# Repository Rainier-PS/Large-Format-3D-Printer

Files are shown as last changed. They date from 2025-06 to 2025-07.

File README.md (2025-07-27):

# Large Format Cartesian 3D Printer

## Project Overview
This is a custom-built large-format Cartesian 3D printer designed for high-quality DIY fabrication with a competitive edge against commercial systems.

### Key Specs
- **Build Volume:** 310 x 310 x 340 mm
- **Motion System:** Cartesian XYZ
- **Controller:** Arduino Mega 2560 + RAMPS 1.4
- **Stepper Drivers:** TMC2209 (ultra-quiet and reliable)
- **Firmware:** Marlin 2.1.2 (custom configuration)
- **Extruder & Hotend:** MK8 extruder + hotend kit
- **Bed:** 24V heated aluminum bed with PEI sheet
- **PSU:** Mean Well LRS-350-24

---

## Why I Made This Project

I wanted to build a production-grade 3D printer that is not only budget-friendly, but also offers a large build area, solid mechanical reliability, and excellent print quality.

This project also serves as a hands-on learning experience where I could improve my skills in:
- **Electronics assembly and integration**
- **CAD modeling and mechanical design**
- **Firmware configuration (Marlin)**
- **Wiring, troubleshooting, and system-level design**

The Hack Club Highway event was the perfect place to begin this journey. With mentorship, resources, and motivation to build something real from the ground up.

Ultimately, I wanted this printer to be **good enough to use as my daily driver**: a machine I can rely on for future projects, prototypes, and creative builds beyond the event itself.

---

## Project Gallery

---

### 3D CAD Model
> *Simplified CAD model for structural representation only. Some non-critical details (e.g., pulleys, belts, LCD) were omitted for simplicity*
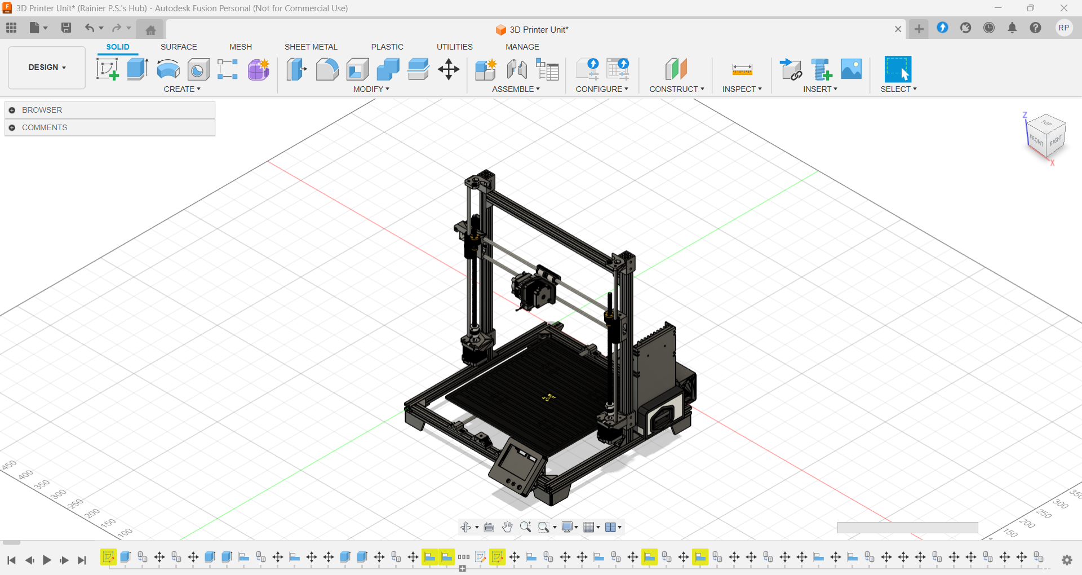
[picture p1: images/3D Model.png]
cad_screenshot


---

### Wiring Diagram
> *Schematic of wiring between Arduino Mega, RAMPS board, endstops, stepper motors, thermistors, and heated bed.*
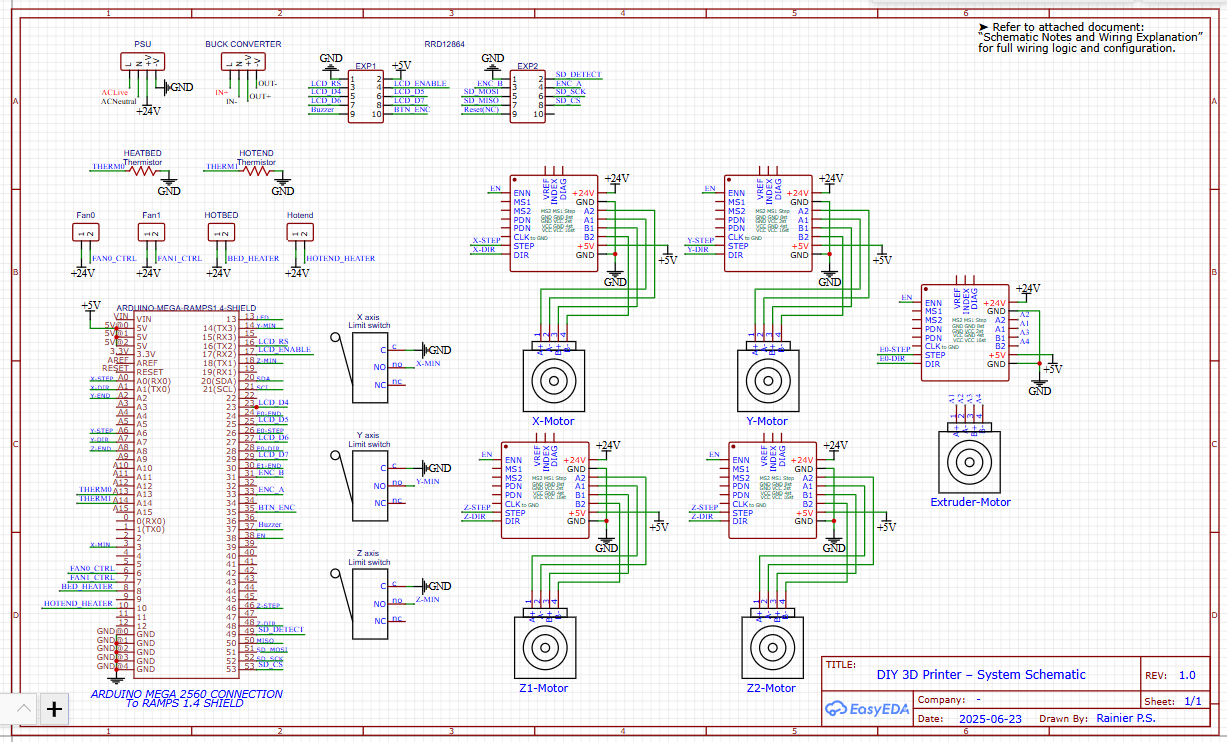
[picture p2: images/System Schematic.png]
wiring_diagram


---

## Wiring Overview  
- **Controller**: Arduino Mega 2560 + RAMPS 1.4  
- **Power**: 24V PSU → RAMPS, 12V buck → Arduino  
- **Endstops**: X, Y, Z (NO → `MIN` pins)  
- **Thermistors**: Hotend (`A13`), Bed (`A14`)  
- **Steppers**: X, Y, Z (dual), E (TMC2209 legacy)  
- **Fans**: Hotend cooling, Electronics cooling  
- **Heaters**: Hotend (`D10`), Bed (`D8`)  

> *[Full wiring details](docs/Schematic%20Notes%20and%20Wiring%20Explanation.txt)*

---

## Bill of Materials (BOM)

| No. | Category | Item | Quantity | Est. Price (USD) | Description / Notes | Link |
|-----|---|---|---|---|---|---|
| 1 | Frame & Structure | 2020 Aluminum Extrusion – 6 m | 1 | $20 | Not Pre-Cut | [Link](https://www.tokopedia.com/aluminiumprofileid/aluminium-extrusion-2020-t-slot-silver-panjang-6-meter-sangat-murah-dan-berkualitas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) |
| 2 | Frame & Structure | Corner Brackets | 10 | $2 | L-Brackets | [Link](https://www.tokopedia.com/leansigma/alumunium-bracket-corner-siku-2020-gusset-corner-profile-2020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) |
| 3 | Frame & Structure | Screws (M5) | 100 pcs | $6 | For frame + brackets | [Link](https://www.tokopedia.com/suburbaut/baut-l-baja-grade-12-9-129-m5x10-m5x12-m5x16-m5x20-m5x25-5-x-10-5-x-12-5-x-16-5-x-20-5-x-25-5x10-5x12-5x16-5x20-5x25-full-drat-bl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) |
| 4 | Frame & Structure | T-nuts (M5) | 100 pcs | $2 | For attaching frame components | [Link](https://www.tokopedia.com/cyber-mm/100pcs-t-nut-m5-baja-karbon-20-series-standar-eropa-10-6-5mm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) |
| 5 | Frame & Structure | Screws (M3) | 100 pcs | $4 | For printed parts & mounts | [Link](https://www.tokopedia.com/3dinjakarta/baut-l-baja-hitam-m3x5-m3x10-m3x16-m3x20-hex-socket-screw-din912-black-steel-m3-x-5-m3-x-10-m3-x-16-m3-x-20-m3x16-eacb6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) |
| 6 | Frame & Structure | Nuts (M3) | 100 pcs | $1 | General purpose M3 nuts | [Link](https://www.tokopedia.com/pulosomeijaya/mur-ss-304-m3-hex-nut-stainless-steel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) |
| 7 | Frame & Structure | Nuts (M3) – Square | 10 pcs | $1 | For 3D printed slots | [Link](https://www.tokopedia.com/3dinjakarta/square-nut-mur-kotak-stainless-steel-304-din557-m3-m4-m5-m6-1731117786386106133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) |
| 8 | Frame & Structure | Rubber Feet | 4 | $2 | Vibration damping | [Link](https://tokopedia.link/z3710SaNqUb) |
| 9 | Linear Motion | Smooth Rods – 8mm × 2300mm | 1 | $6 | Not Pre-Cut | [Link](https://tokopedia.link/DO7ZdYfNqUb) |
| 10  | Linear Motion | Linear Bearings (LM8UU) | 8 | $3 | 2 for each axis | [Link](https://tokopedia.link/DO7ZdYfNqUb) |
| 11  | Linear Motion | Linear Bearings (SC8UU) | 4 | $5 | 2 for each rod (Y axis) | [Link](https://www.tokopedia.com/cncstorebandung/scs8uu-sc8uu-bearing-slide-blok-8mm-lm8uu-3d-printing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) |
| 12  | Linear Motion | GT2 Belt (6mm width) | 3 meters | $3 | 1.5m each for X and Y | [Link](https://www.tokopedia.com/centi-store/timing-belt-gt2-6mm-untuk-3d-printer-meteran-open-loop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) |
| 13  | Linear Motion | Idler Pulley with Bearings | 2 | $2 | One for each axis return path | [Link](https://www.tokopedia.com/xyzhobby/gt2-20t-w6-b3-idler-pulley-tooth-toothless-2gt-20teeth-width-6mm-bore-3mm-20-teeth-pitch-2mm-2-3-6-mm-3d-printer-teeth-8c659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) |
| 14  | Linear Motion | Motor Pulley | 2 | $1 | 1 for X, 1 for Y | [Link](https://www.tokopedia.com/solarperfect/3d-printer-gt2-16-teeth-timing-pulley-aluminium-bore-5mm-untuk-6mm-2gt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) |
| 15  | Linear Motion | T8 Leadscrew + Brass Nut | 2 sets | $9 | Leadscrew-driven Z motion | [Link](https://www.tokopedia.com/centi-store/t8-8mm-pitch-2mm-lead-2mm-nut-leadscrew-lead-screw-350mm-350-mm-35cm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) |
| 16  | Linear Motion | Flexible Coupler (5mm to 8mm) | 2 | $2 | Stepper → leadscrew coupling | [Link](https://www.tokopedia.com/rajawali3d/flexible-coupling-d19-l25-5x8-mm-coupler-alumunium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) |
| 17  | Electronics | NEMA17 Stepper Motor | 4 | $47 | X,Y,Z (2x) | [Link](https://www.tokopedia.com/mentariputri/nema17-stepper-motor-1-8a-torsi-tinggi-17hs8401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) |
| 18  | Electronics | TMC2209 Stepper Driver | 5 | $14 | Quiet, reliable stepper control | [Link](https://www.tokopedia.com/cncstorebandung/driver-stepper-mks-tmc2209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) |
| 19  | Electronics | Arduino Mega 2560 | 1 | $13 | Main controller | [Link](https://www.tokopedia.com/rajacell/arduinoo-mega-2560-r3-16u2-mega2560-high-quality-5v-16mhz-dev-board-mega2560-board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) |
| 20  | Electronics | RAMPS 1.4 Shield | 1 | $7 | Stepper and I/O shield | [Link](https://www.tokopedia.com/rajawali3d/high-quality-ramps-v1-4-3d-printer-control-panel-shield-for-mega-2560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) |
| 21  | Electronics | Full Graphic Smart Controller (LCD + SD) | 1 | $9 | Screen + SD card input | [Link](https://tokopedia.link/LF29UHXNqUb) |
| 22  | Electronics | Mechanical Endstops | 3 | $2 | For X, Y, Z homing | [Link](https://www.tokopedia.com/solarperfect/mechanical-limit-switch-endstop-for-3d-printers-ramps-1-4-for-reprap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) |
| 24  | Electronics | Signal Wires, Dupont, JST, etc. | - | $4 | For endstops, fans, sensors | – |
| 25  | Electronics | Heat Shrink Tubes, Ferrules, Crimps | - | $2 | For safe wire connections | – |
| 26  | Electronics | 24V to 12V Buck Converter | 1 | $2 | Lowers voltage to Arduino | [Link](https://www.tokopedia.com/tokoasia-jogja/local-stock-lm2596s-buck-converter-dc-dc-step-down-voltage-regulator-36v-24v-12v-to-5v-2a-volt-digital-display-2596s-1730718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) |
| 27  | Electronics | Barrel Jack to Bare Wire | 1 | $1 | For powering Arduino | [Link](https://www.tokopedia.com/jiwanala/kabel-jack-cable-5-5x21mm-male-bare-end-buntung-25cm-5a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) |
| 28  | Extruder & Hotend | MK8 Extruder Set | 1 | $17 | Extruder + Hotend & Thermistor | [Link](https://tokopedia.link/Ti3EJZONqUb) |
| 29  | Extruder & Hotend | NEMA17 Stepper Motor L-Bracket | 1 | $1 | For mounting extruder motor | [Link](https://www.tokopedia.com/rajawali3d/bracket-l-untuk-stepper-motor-42-nema-17-steel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) |
| 30  | Extruder & Hotend | 4010 Hotend Cooling Fan | 1 | $3 | Blows on heatsink | – |
| 31  | Extruder & Hotend | 5015 Part Cooling Fan | 1 | $4 | Cools printed filament | – |
| 32  | Extruder & Hotend | Thermistor (NTC 100K) | 2 | $3 | Temperature sensor | [Link](https://tokopedia.link/bmOpcOw4qUb) |
| 33  | Build Platform | Heated Bed – 310×310mm, 24V | 1 | $14 | Large aluminum PCB bed | [Link](https://tokopedia.link/6d3Pe8ANqUb) |
| 34  | Build Platform | PEI Sheet or Glass Plate | 1 | $9 | Smooth print surface | [Link](https://www.tokopedia.com/xyzhobby/kingroon-flexible-magnetic-heatbed-235x235mm-310x310mm-3d-printer-235mm-310mm-235-310-mm-235x235-310x310-hot-bed-sheet-a-b-soft-ma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) |
| 35  | Build Platform | Insulation (cork pad or silicone) | 1 | $3 | Under-bed heat efficiency | [Link](https://tokopedia.link/mQp9XiKNqUb) |
| 36  | Build Platform | Y-Axis Bed Carriage Plate | 1 | $18 | Slides on rods with SC8UU | [Link](https://tokopedia.link/2MtuPYFNqUb) |
| 37  | Build Platform | Bed Leveling Kit | 1 | $3 | Spring screws + knobs | [Link](https://www.tokopedia.com/technohance/biqu-3d-printer-parts-heat-bed-spring-leveling-kit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) |
| 38  | Power & Safety | Mean Well LRS-350-24 PSU (24V, 350W) | 1 | $23 | Reliable 24V power | [Link](https://tokopedia.link/Zbn0BSsNqUb) |
| 39  | Power & Safety | AC Plug + Switch + Fuse | 1 | $2 | Main power switch + safety | [Link](https://tokopedia.link/S09f4BvNqUb) |
| 40  | 3D Printed Components  | X-Axis Carriage | 1 | $2 | Holds hotend, belt clamp, fans | – |
| 41  | 3D Printed Components  | Z Stepper Mounts | 2 | $2 | Holds Z steppers at bottom | – |
| 42  | 3D Printed Components  | X-Axis Motor Mount | 1 | $3 | Attaches Nema17 to brass nut | – |
| 43  | 3D Printed Components  | Y Stepper and Idler Mount | 2 | $2 | Front/back Y axis | – |
| 44  | 3D Printed Components  | X Idler Mount | 1 | $3 | Tensioner opposite X motor | – |
| 45  | 3D Printed Components  | LCD Case / Mount | 1 | $3 | LCD case | – |
| 46  | 3D Printed Components  | Z-Axis Screw & Rod Holder | 2 | $4 | Top Smooth Rod and Leadscrew Holder | – |
| 47  | 3D Printed Components  | PSU Mount Bracket | 1 | $4 | Mount Mean Well PSU to frame | – |
| 48  | 3D Printed Components  | Belt Tensioners (X, Y) | 2–4 | – | Belt clamping and adjustment | – |
| 49  | 3D Printed Components  | Y-Axis Belt Holder | 1 | $1 | Belt Holder for Heatbed Carriage | – |
| 50  | 3D Printed Components  | 3D Printed Frame Feet | 4 | $6 | 4x Feet for 3D Printer Frame | – |
| 51  | 3D Printed Components  | 3D Printed Electronics Box | 1 | $5 | Arduino Mega and RAMPS Enclosure | – |
| 52  | 3D Printed Components  | Misc. Brackets, Cable Holders, etc. | Several | $2 | Miscellaneous supports | – |
| 53  | Misc & Assembly | Screws, Nuts, Washers | Assorted | $5 | M3/M4/M5 types for various mounts | – |
| 54  | Misc & Assembly | Zip Ties / Cable Sleeves | – | $1 | Cable management | – |
| 55  | Misc & Assembly | Kapton Tape | 1 | $1 | Heat resistant, for thermistor & bed | [Link](https://www.tokopedia.com/towajo/solasi-selotip-lakban-isolasi-anti-panas-kapton-heat-resistant-tape-polyimide-high-temperature-adhesive-33m-x10mm-022b9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) 
| 56  | Misc & Assembly  | AC Power Cable | 1 | $4 | AC Cable for main power  | [Link](https://www.tokopedia.com/ventionacc/vention-kabel-power-c13-connector-3-prong-1-8m-eu-plug-zcg-1730865969691199429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) |

Total: $323

>* Prices converted from IDR to USD using Google Currency Converter (June 2025)

>  Prices are rounded up to the nearest whole dollar per item (maximum increase < $1).																									

> A downloadable CSV is available at `BOM.csv`.

---

## File Structure

```bash
project-root/
├── README.md
├── JOURNAL.md
├── BOM.csv
├── /cad/
├── /images/
├── /docs/

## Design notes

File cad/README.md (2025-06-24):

## 📦 CAD Files

Due to GitHub’s file size limits, the full CAD archive is hosted on Google Drive.

👉 [📁 Open CAD Files Folder on Google Drive](https://drive.google.com/drive/folders/1XvsMu-9OImcrpDDpuesnx_VVXOSItciy)

> Contains:  
> • `3D Printer Unit.f3d`  
> • `3D Printer Unit.stp / .step`  
> • Zipped version for easier download  
> All files are organized in a folder for convenience.

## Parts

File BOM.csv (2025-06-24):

No. | Category | Item | Quantity | Est. Price (USD) | Description / Notes | Link
1 | Frame & Structure | 2020 Aluminum Extrusion – 6 m | 1 | $20 | Not Pre-Cut | https://www.tokopedia.com/aluminiumprofileid/aluminium-extrusion-2020-t-slot-silver-panjang-6-meter-sangat-murah-dan-berkualitas
2 | Frame & Structure | Corner Brackets | 10 | $2 | L-Brackets | https://www.tokopedia.com/leansigma/alumunium-bracket-corner-siku-2020-gusset-corner-profile-2020
3 | Frame & Structure | Screws (M5) | 100 pcs | $6 | For frame + brackets | https://www.tokopedia.com/suburbaut/baut-l-baja-grade-12-9-129-m5x10-m5x12-m5x16-m5x20-m5x25-5-x-10-5-x-12-5-x-16-5-x-20-5-x-25-5x10-5x12-5x16-5x20-5x25-full-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
4 | Frame & Structure | T-nuts (M5) | 100 pcs | $2 | For attaching frame components | https://www.tokopedia.com/cyber-mm/100pcs-t-nut-m5-baja-karbon-20-series-standar-eropa-10-6-5mm
5 | Frame & Structure | Screws (M3) | 100 pcs | $4 | For printed parts & mounts | https://www.tokopedia.com/3dinjakarta/baut-l-baja-hitam-m3x5-m3x10-m3x16-m3x20-hex-socket-screw-din912-black-steel-m3-x-5-m3-x-10-m3-x-16-m3-x-20-m3x16-eacb6
6 | Frame & Structure | Nuts (M3) | 100 pcs | $1 | General purpose M3 nuts | https://www.tokopedia.com/pulosomeijaya/mur-ss-304-m3-hex-nut-stainless-steel
7 | Frame & Structure | Nuts (M3) - Square | 10 pcs | $1 | For 3D printed slots | https://www.tokopedia.com/3dinjakarta/square-nut-mur-kotak-stainless-steel-304-din557-m3-m4-m5-m6-1731117786386106133
8 | Frame & Structure | Rubber Feet | 4 | $2 | Vibration damping | https://tokopedia.link/z3710SaNqUb
9 | Linear Motion | Smooth Rods – 8mm × 2300mm | 1 | $6 | Not Pre-Cut | https://tokopedia.link/DO7ZdYfNqUb
10 | Linear Motion | Linear Bearings (LM8UU) | 8 | $3 | 2 for each axis | https://tokopedia.link/DO7ZdYfNqUb
11 | Linear Motion | Linear Bearings (SC8UU) | 4 | $5 | 2 for each rod (Y axis) | https://www.tokopedia.com/cncstorebandung/scs8uu-sc8uu-bearing-slide-blok-8mm-lm8uu-3d-printing
12 | Linear Motion | GT2 Belt (6mm width) | 3 meters | $3 | 1.5m each for X and Y | https://www.tokopedia.com/centi-store/timing-belt-gt2-6mm-untuk-3d-printer-meteran-open-loop
13 | Linear Motion | Idler Pulley with Bearings | 2 | $2 | One for each axis return path | https://www.tokopedia.com/xyzhobby/gt2-20t-w6-b3-idler-pulley-tooth-toothless-2gt-20teeth-width-6mm-bore-3mm-20-teeth-pitch-2mm-2-3-6-mm-3d-printer-teeth-8c659
14 | Linear Motion | Motor Pulley | 2 | $1 | 1 for X, 1 for Y | https://www.tokopedia.com/solarperfect/3d-printer-gt2-16-teeth-timing-pulley-aluminium-bore-5mm-untuk-6mm-2gt
15 | Linear Motion | T8 Leadscrew (Z-axis) + Brass Nut | 2 sets | $9 | Leadscrew-driven Z motion | https://www.tokopedia.com/centi-store/t8-8mm-pitch-2mm-lead-2mm-nut-leadscrew-lead-screw-350mm-350-mm-35cm
16 | Linear Motion | Flexible Coupler (5mm to 8mm) | 2 | $2 | Stepper → leadscrew coupling | https://www.tokopedia.com/rajawali3d/flexible-coupling-d19-l25-5x8-mm-coupler-alumunium
17 | Electronics | NEMA17 Stepper Motor | 4 | $47 | X,Y, Z (2x) | https://www.tokopedia.com/mentariputri/nema17-stepper-motor-1-8a-torsi-tinggi-17hs8401
18 | Electronics | TMC2209 Stepper Driver | 5 | $14 | Quiet, reliable stepper control | https://www.tokopedia.com/cncstorebandung/driver-stepper-mks-tmc2209
19 | Electronics | Arduino Mega 2560 | 1 | $13 | Main controller | https://www.tokopedia.com/rajacell/arduinoo-mega-2560-r3-16u2-mega2560-high-quality-5v-16mhz-dev-board-mega2560-board
20 | Electronics | RAMPS 1.4 Shield | 1 | $7 | Stepper and I/O shield | https://www.tokopedia.com/rajawali3d/high-quality-ramps-v1-4-3d-printer-control-panel-shield-for-mega-2560
21 | Electronics | Full Graphic Smart Controller (LCD + SD) | 1 | $9 | Screen + SD card input | https://tokopedia.link/LF29UHXNqUb
22 | Electronics | Mechanical Endstops | 3 | $2 | For X, Y, Z homing | https://www.tokopedia.com/solarperfect/mechanical-limit-switch-endstop-for-3d-printers-ramps-1-4-for-reprap
23 | Electronics | Power Wires (14 & 18 AWG) | 12 meters | $5 | For heated bed, hotend, motors | https://www.tokopedia.com/pitoserba/kabel-awg-18-tinned-cu-awg18-up-to-80-celcius-per-meter-hitam
24 | Electronics | Signal Wires, Dupont, JST, etc. | - | $4 | For endstops, fans, sensors
25 | Electronics | Heat Shrink Tubes, Ferrules, Crimps | - | $2 | For safe wire connections
26 | Electronics | 24V to 12V Buck Converter | 1 | $2 | Lowers voltage to Arduino | https://www.tokopedia.com/tokoasia-jogja/local-stock-lm2596s-buck-converter-dc-dc-step-down-voltage-regulator-36v-24v-12v-to-5v-2a-volt-digital-display-2596s-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
27 | Electronics | Barrel Jack to Bare Wire | 1 | $1 | For powering Arduino | https://www.tokopedia.com/jiwanala/kabel-jack-cable-5-5x21mm-male-bare-end-buntung-25cm-5a
28 | Extruder & Hotend | MK8 Extruder Set | 1 | $17 | Extruder + Hotend & Thermistor | https://tokopedia.link/Ti3EJZONqUb
29 | Extruder & Hotend | NEMA17 Stepper Motor L-Bracket | 1 | $1 | For mounting extruder motor | https://www.tokopedia.com/rajawali3d/bracket-l-untuk-stepper-motor-42-nema-17-steel
30 | Extruder & Hotend | 4010 Hotend Cooling Fan | 1 | $3 | Blows on heatsink
31 | Extruder & Hotend | 5015 Part Cooling Fan | 1 | $4 | Cools printed filament
32 | Extruder & Hotend | Thermistor (NTC 100K) | 2 | $3 | Temperature sensor | https://tokopedia.link/bmOpcOw4qUb
33 | Build Platform | Heated Bed – 310×310mm, 24V | 1 | $14 | Large aluminum PCB bed | https://tokopedia.link/6d3Pe8ANqUb
34 | Build Platform | PEI Sheet or Glass Plate | 1 | $9 | Smooth print surface | https://www.tokopedia.com/xyzhobby/kingroon-flexible-magnetic-heatbed-235x235mm-310x310mm-3d-printer-235mm-310mm-235-310-mm-235x235-310x310-hot-bed-sheet-a-b-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
35 | Build Platform | Insulation (cork pad or silicone) | 1 | $3 | Under-bed heat efficiency | https://tokopedia.link/mQp9XiKNqUb
36 | Build Platform | Y-Axis Bed Carriage Plate | 1 | $18 | Slides on rods with SC8UU | https://tokopedia.link/2MtuPYFNqUb
37 | Build Platform | Bed Leveling Kit | 1 | $3 | Spring screws + knobs | https://www.tokopedia.com/technohance/biqu-3d-printer-parts-heat-bed-spring-leveling-kit
38 | Power & Safety | Mean Well LRS-350-24 PSU (24V, 350W) | 1 | $23 | Reliable 24V power | https://tokopedia.link/Zbn0BSsNqUb
39 | Power & Safety | AC Plug + Switch + Fuse | 1 | $2 | Main power switch + safety | https://tokopedia.link/S09f4BvNqUb
40 | 3D Printed Components | X-Axis Carriage | 1 | $2 | Holds hotend, belt clamp, fans
41 | 3D Printed Components | Z Stepper Mounts | 2 | $2 | Holds Z steppers at bottom
42 | 3D Printed Components | X-Axis Motor Mount | 1 | $3 | Attaches Nema17 to brass nut
43 | 3D Printed Components | Y Stepper and Idler Mount | 2 | $2 | Front/back Y axis
44 | 3D Printed Components | X Idler Mount | 1 | $3 | Tensioner opposite X motor
45 | 3D Printed Components | LCD Case / Mount | 1 | $3 | LCD case
46 | 3D Printed Components | Z-Axis Screw & Rod Holder | 2 | $4 | Top Smooth Rod and Leadscrew Holder
47 | 3D Printed Components | PSU Mount Bracket | 1 | $4 | Mount Mean Well PSU to frame
48 | 3D Printed Components | Belt Tensioners (X, Y) | 2–4 | - | Belt clamping and adjustment
 | 3D Printed Components | Y-Axis Belt Holder | 1 | $1 | Belt Holder for Heatbed Carriage
 | 3D Printed Components | 3D Printed Frame Feet | 4 | $6 | 4x Feet for 3D Printer Frame
 | 3D Printed Components | 3D Printed Electronics Box | 1 | $5 | Arduino Mega and RAMPS 1.4 Enclosure
49 | 3D Printed Components | Misc. Brackets, cable holders, etc. | Several | $2 | Miscellaneous supports
50 | Misc & Assembly | Screws, Nuts, Washers | Assorted | $5 | M3/M4/M5 types for various mounts
51 | Misc & Assembly | Zip Ties / Cable Sleeves | - | $1 | Cable management
52 | Misc & Assembly | Kapton Tape | 1 | $1 | Heat resistant, for thermistor + bed insulation | https://www.tokopedia.com/towajo/solasi-selotip-lakban-isolasi-anti-panas-kapton-heat-resistant-tape-polyimide-high-temperature-adhesive-33m-x10mm-022b9
* Prices converted from IDR to USD using Google Currency Converter (June 2025)
Prices are rounded up to the nearest whole dollar per item (maximum increase < $1).

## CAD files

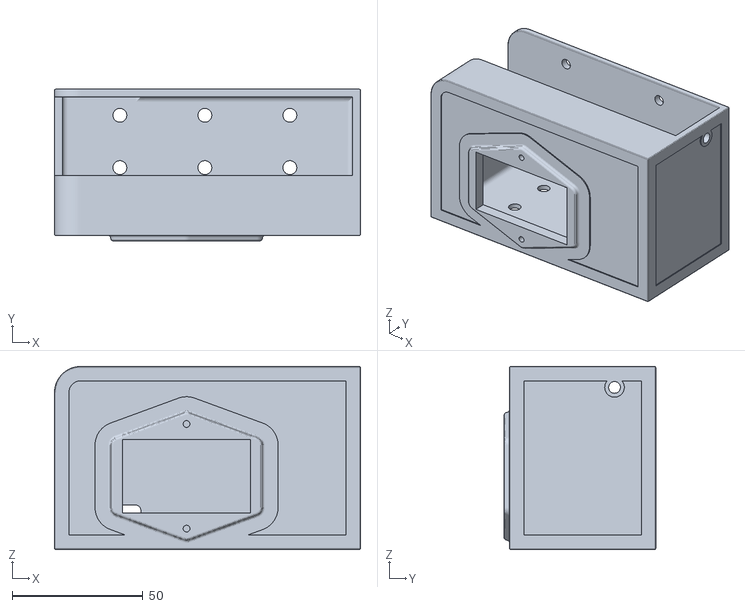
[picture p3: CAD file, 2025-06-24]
cad/Parts/Power_Supply_Holder.stl
117.0 x 58.0 x 70.0

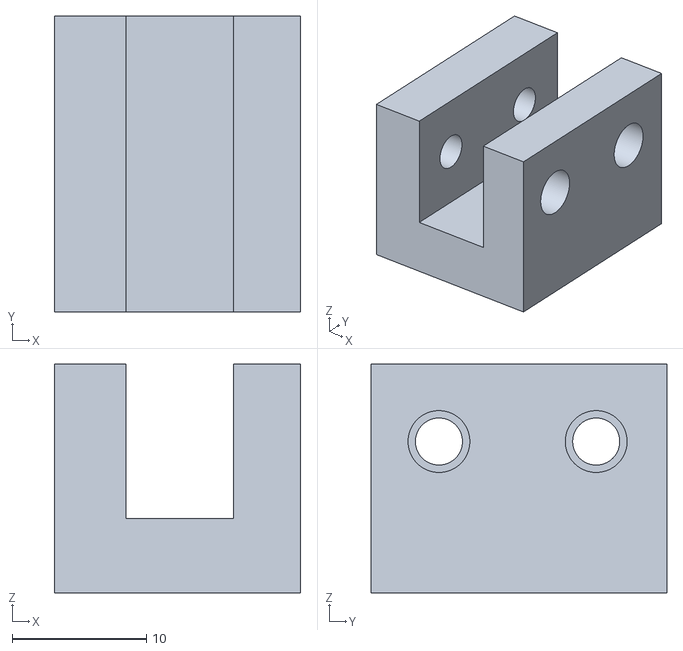
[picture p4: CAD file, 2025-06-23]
cad/Parts/Y_Belt_Holder.stl
18.3 x 22.0 x 17.0

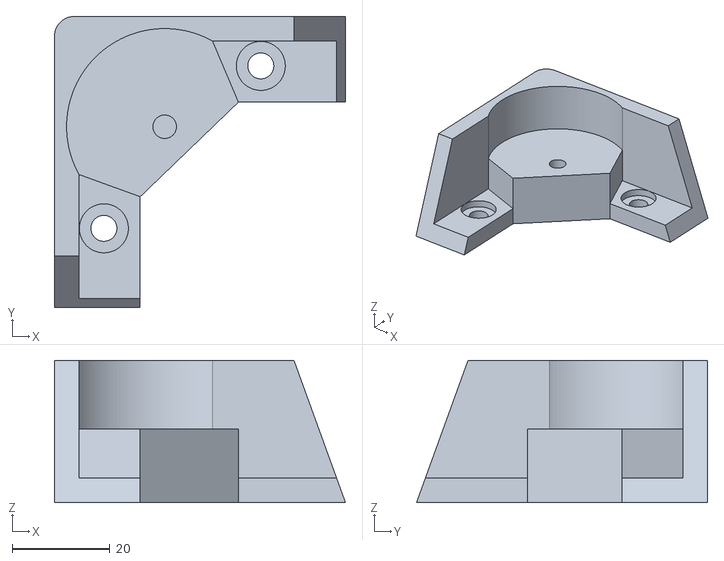
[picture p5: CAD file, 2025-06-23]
cad/Parts/4 x Foot.stl
59.4 x 59.4 x 29.0

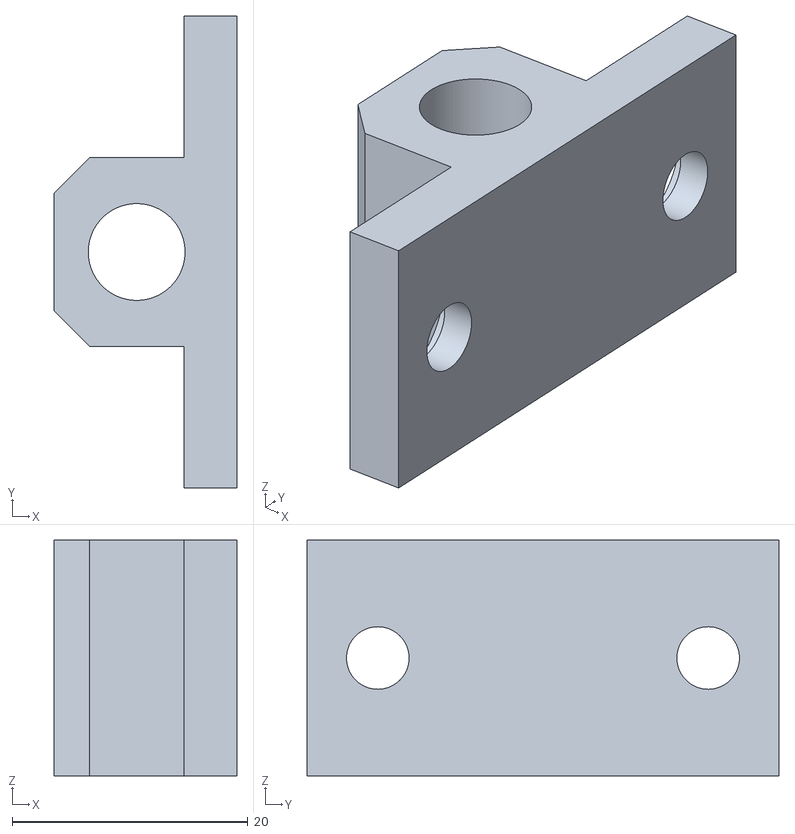
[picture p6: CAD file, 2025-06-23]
cad/Parts/4 x Y_Rod_Mount.stl
15.5 x 40.0 x 20.0

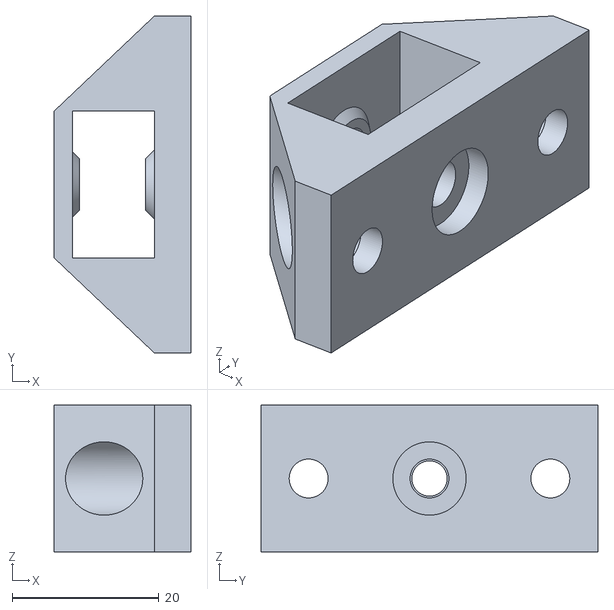
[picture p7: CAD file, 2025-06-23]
cad/Parts/Y_Idler_Mount.stl
18.7 x 46.0 x 20.0

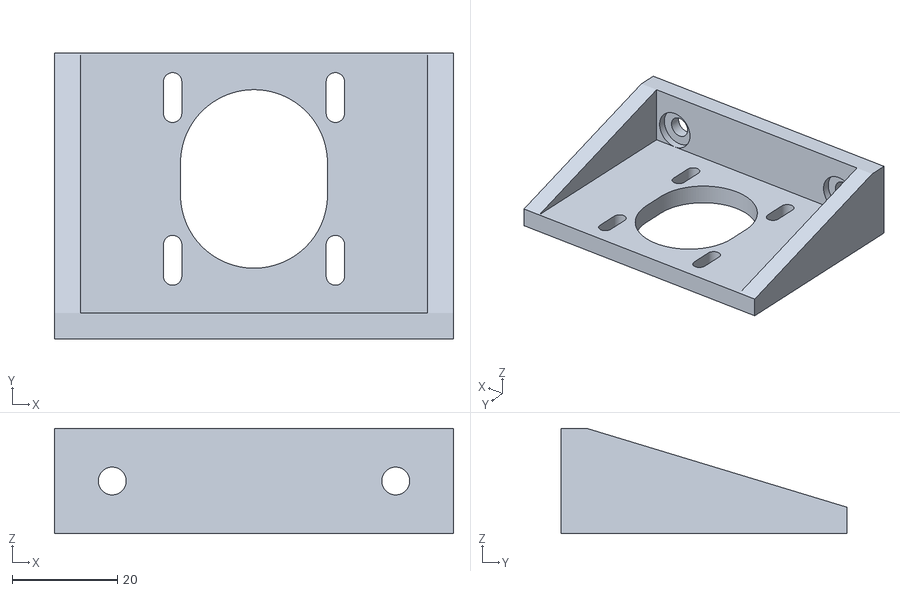
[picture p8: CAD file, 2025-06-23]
cad/Parts/Y_Motor_Mount.stl
76.0 x 54.5 x 20.0

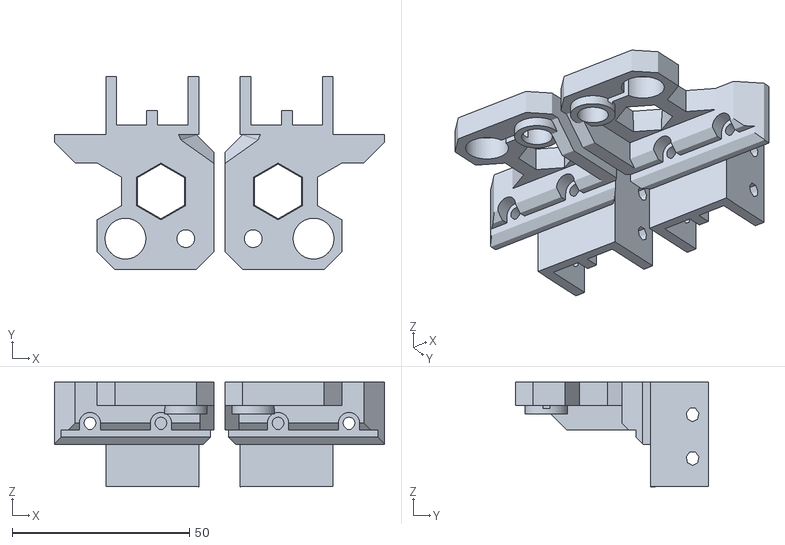
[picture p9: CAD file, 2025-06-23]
cad/Parts/Z-Axis Motor Mount.stl
93.0 x 54.4 x 29.5

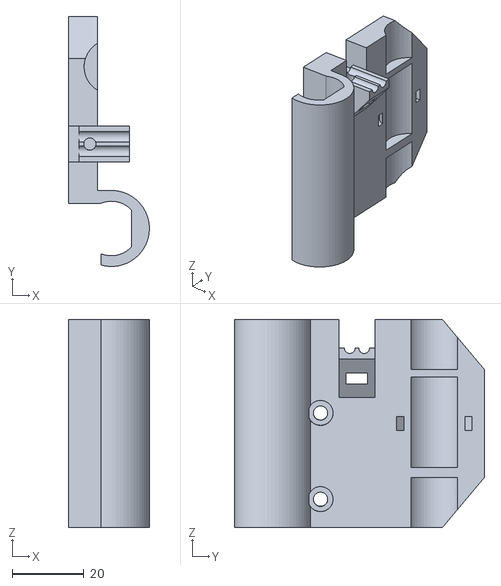
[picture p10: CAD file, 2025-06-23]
cad/Parts/X-Carriage-MK8.stl
22.5 x 69.6 x 58.0

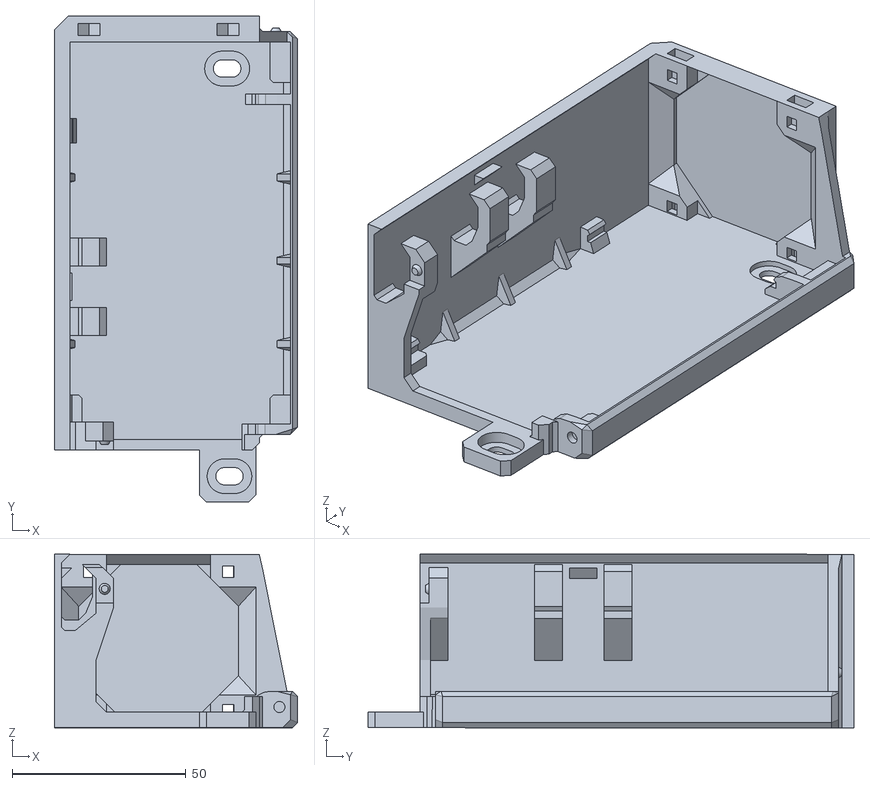
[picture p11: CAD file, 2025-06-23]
cad/Parts/dasaki_ramps_enclosure_base_2020.stl
70.1 x 140.0 x 50.0

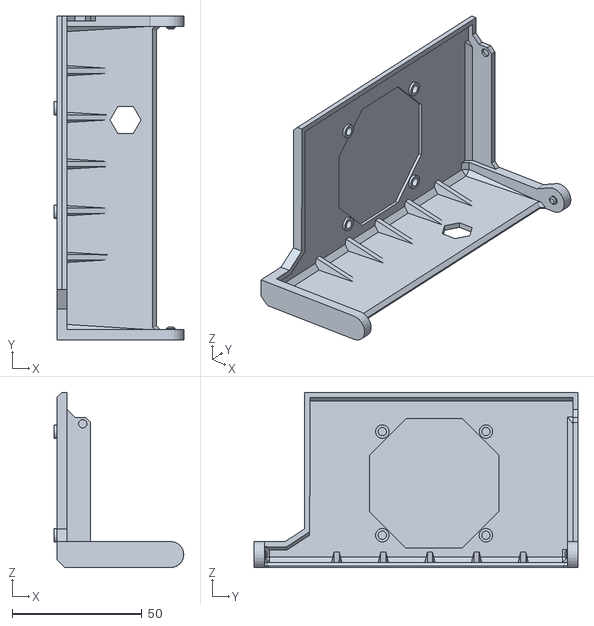
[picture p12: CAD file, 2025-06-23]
cad/Parts/dasaki_ramps_enclosure_cover_v2.stl
50.0 x 125.0 x 67.6

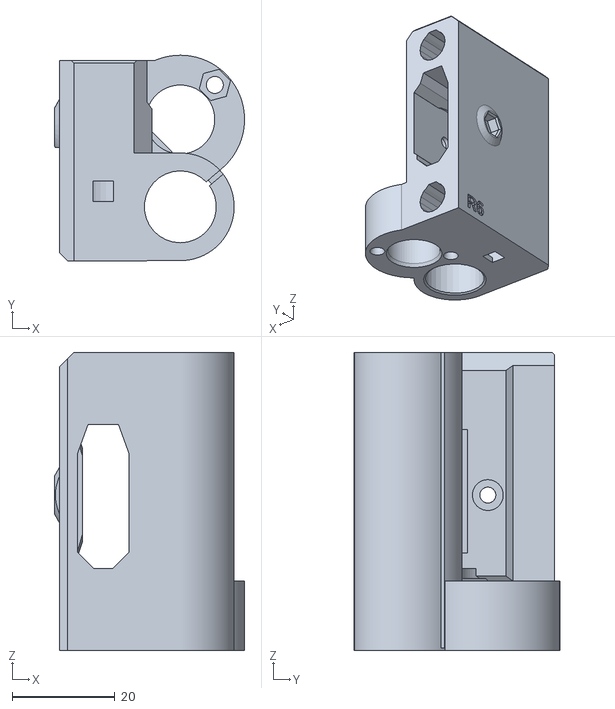
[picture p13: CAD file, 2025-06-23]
cad/Parts/x-end-idler.stl
37.0 x 40.0 x 58.0

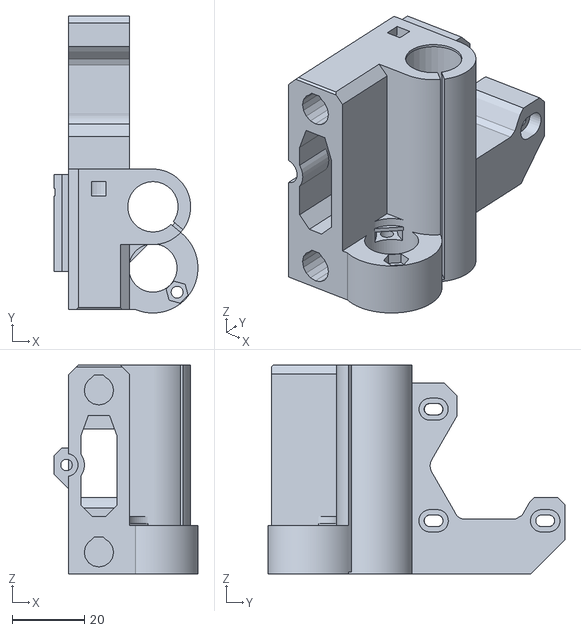
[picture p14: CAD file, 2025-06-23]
cad/Parts/x-end-motor.stl
40.0 x 82.5 x 58.0

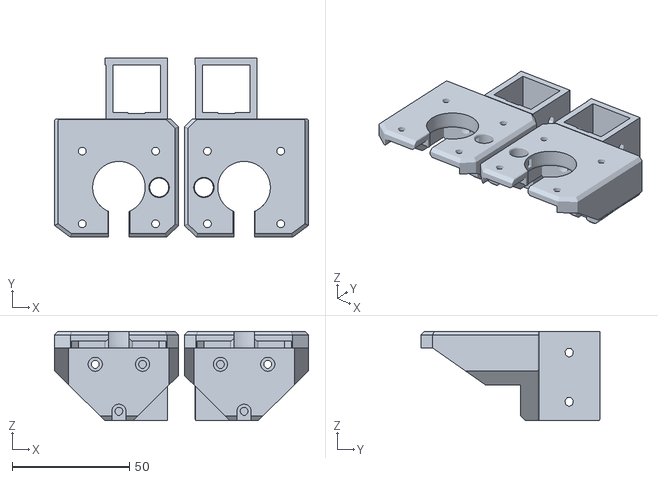
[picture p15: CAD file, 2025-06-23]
cad/Parts/Z-Axis Rod and Leadscrew Bracket.stl
108.3 x 76.5 x 38.0

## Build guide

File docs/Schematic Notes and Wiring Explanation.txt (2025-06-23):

Schematic Notes – DIY 3D Printer (RAMPS 1.4 + Arduino Mega 2560 + TMC2209)

Power System:
- Main PSU: 24V DC input from AC (Live/Neutral).
- A buck converter steps 24V down to 12V and powers the Arduino Mega via the barrel jack (VIN).
- The 24V rail powers motors, hotend, heated bed, and fans.
- 5V logic power is generated by the Arduino Mega’s onboard regulator.

Motor Drivers – TMC2209 (Legacy Mode):
- STEP, DIR, and EN pins are used; no UART communication for now.
- PDN/DIAG left unconnected for future UART upgrade.
- Motors powered by 24V; logic powered by 5V from Mega.
- Dual Z motors use separate TMC2209 drivers but share STEP, DIR, and EN pins.
- MS1/MS2 left floating (defaults used).

Thermistors:
- Hotend thermistor (THERM0) → A13.
- Heated bed thermistor (THERM1) → A14.
- 10k NTC type. RAMPS includes internal pull-up resistors.

Heaters and Fans:
- Hotend heater → D10.
- Heated bed heater → D8.
- Fan0 (hotend cooling) → D9.
- Fan1 added for board/driver cooling.

LCD Display (RRD12864):
- Connected via EXP1 and EXP2 headers.
- Includes SD card and rotary encoder.
- Match wiring to specific display module.

Limit Switches:
- X, Y, Z limit switches wired to MIN pins.
- Normally Open (NO) type. COM → GND, NO → signal.
- Pull-ups handled by firmware or RAMPS.

Labeling and Connections:
- Use clear labels: +24V, +5V, GND.
- VIN not shown on Mega symbol; powered through buck to barrel jack.

Additional Notes:
- PDN/DIAG left unconnected for now.
- EN pins can be shared and labeled "EN".
- Microstepping (MS1/MS2) unused for now.
- PSU symbol uses 4 pins: L, N, +V (24V), GND.

Future Expansion:
- UART mode (connect PDN/DIAG to TX/RX).
- Optional: filament sensor, bed leveling probe, extra fans.
- Add inline fuses, TVS diodes for protection.
- Optional indicator LEDs.

Final Remarks:
- Schematic assumes RAMPS is stacked on the Arduino Mega.
- RAMPS is not shown as a separate symbol; Mega is wired directly.
- Compatible with Marlin firmware (legacy mode).

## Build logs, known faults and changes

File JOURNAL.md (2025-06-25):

# JOURNAL.md – Large Format DIY 3D Printer

**Total Time Spent: 52 hours**
**Duration: 15–23 June 2025**
**Daily Avg: \~5 hours**

---

## 15 June 2025

* **Time Spent:** 5 hours
* **Activities:**

  * Defined project goals and design constraints
  * Compared Cartesian vs CoreXY vs Delta layouts
  * Chose Cartesian for simplicity and rigidity
  * Began sketching rough layout ideas and BOM draft
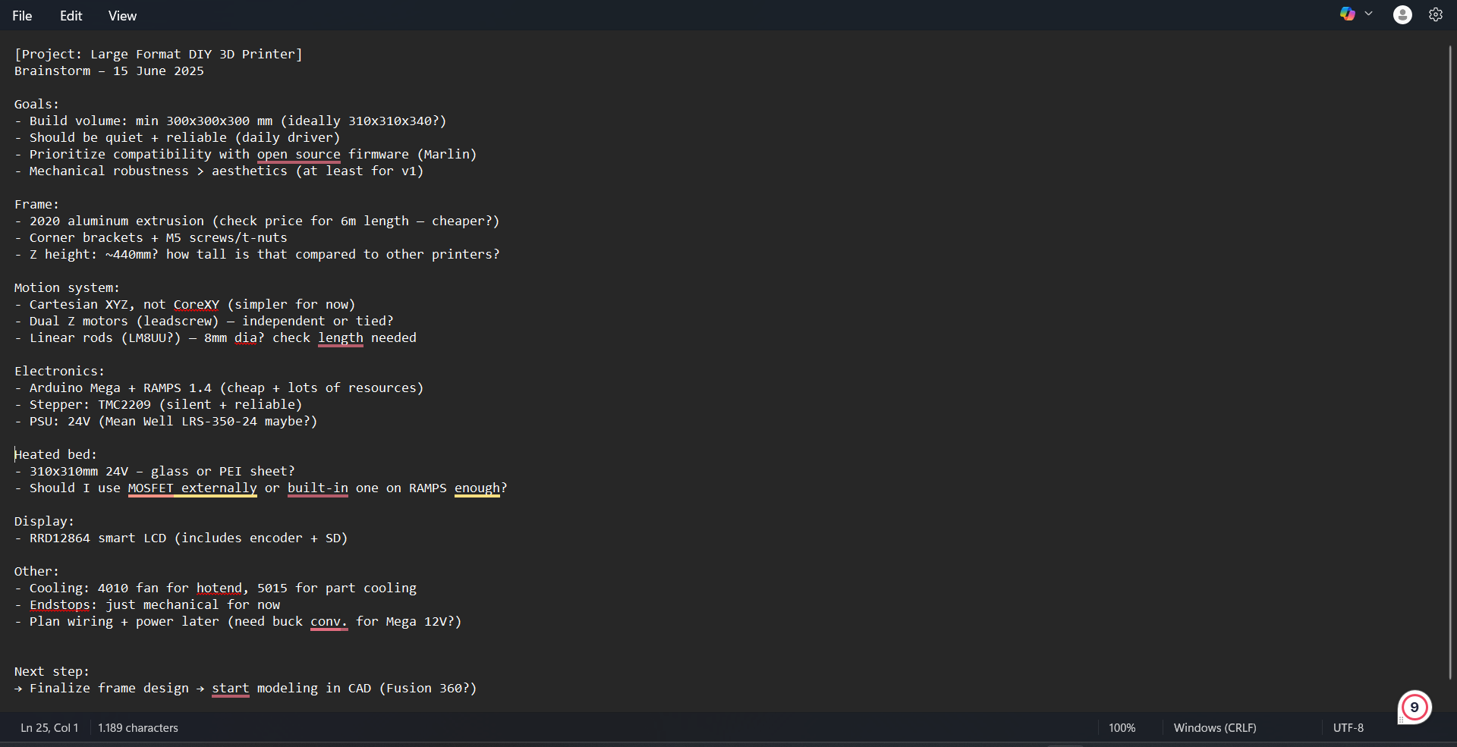
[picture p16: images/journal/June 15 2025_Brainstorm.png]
Brainstorm
* **Image:** 

---

## 16 June 2025

* **Time Spent:** 5.5 hours
* **Activities:**

  * Finalized component list and shortlists major parts
  * Designed and sketched rough dimensions for frame
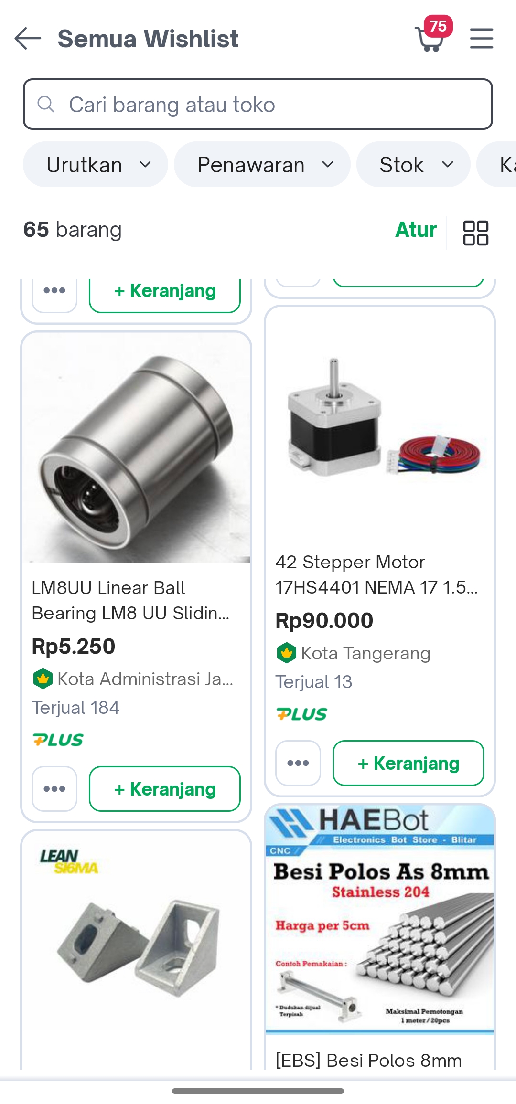
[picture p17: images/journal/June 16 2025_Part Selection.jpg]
Part Selection
* **Image:** 

---

## 17 June 2025

* **Time Spent:** 5.5 hours
* **Activities:**

  * Started 3D modeling using Fusion 360
  * Created full frame structure using 2020 extrusions
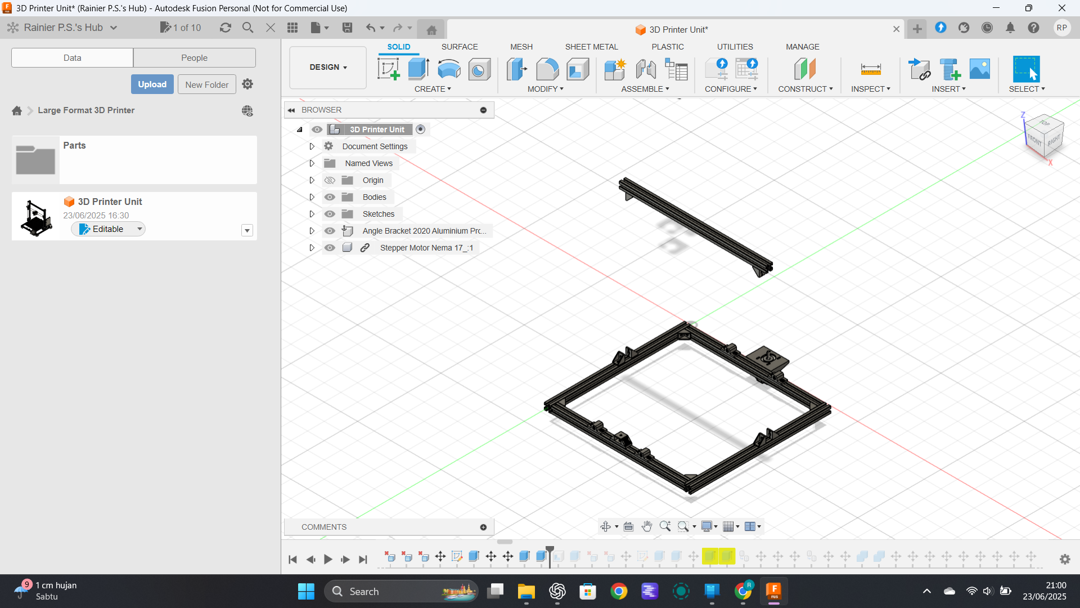
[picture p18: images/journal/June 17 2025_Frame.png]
Frame
* **Image:** 

---

## 18 June 2025

* **Time Spent:** 5 hours
* **Activities:**

  * Modeled Y-axis smooth rods and bearing holders
  * Modeled Z-axis motor mounts, leadscrew guides, and couplers
  * Modeled Z vertical supports and lead nut mounts
  * Added placeholders for hotend and X-carriage
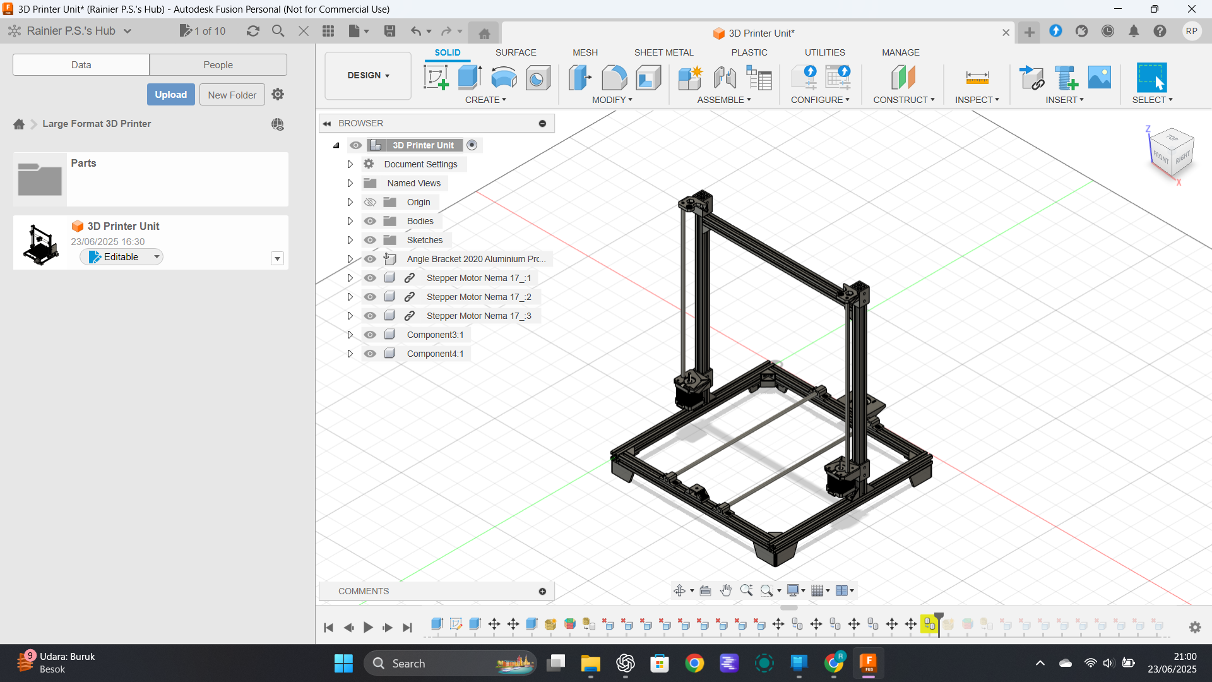
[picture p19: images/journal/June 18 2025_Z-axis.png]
Z-axis
* **Image:** 

---

## 19 June 2025

* **Time Spent:** 5.5 hours
* **Activities:**

  * Finished modeling X-axis assembly with motor, pulley, and belt path
  * Created toolhead and carriage mount for MK8 extruder
  * Verified spacing between axes and fitment
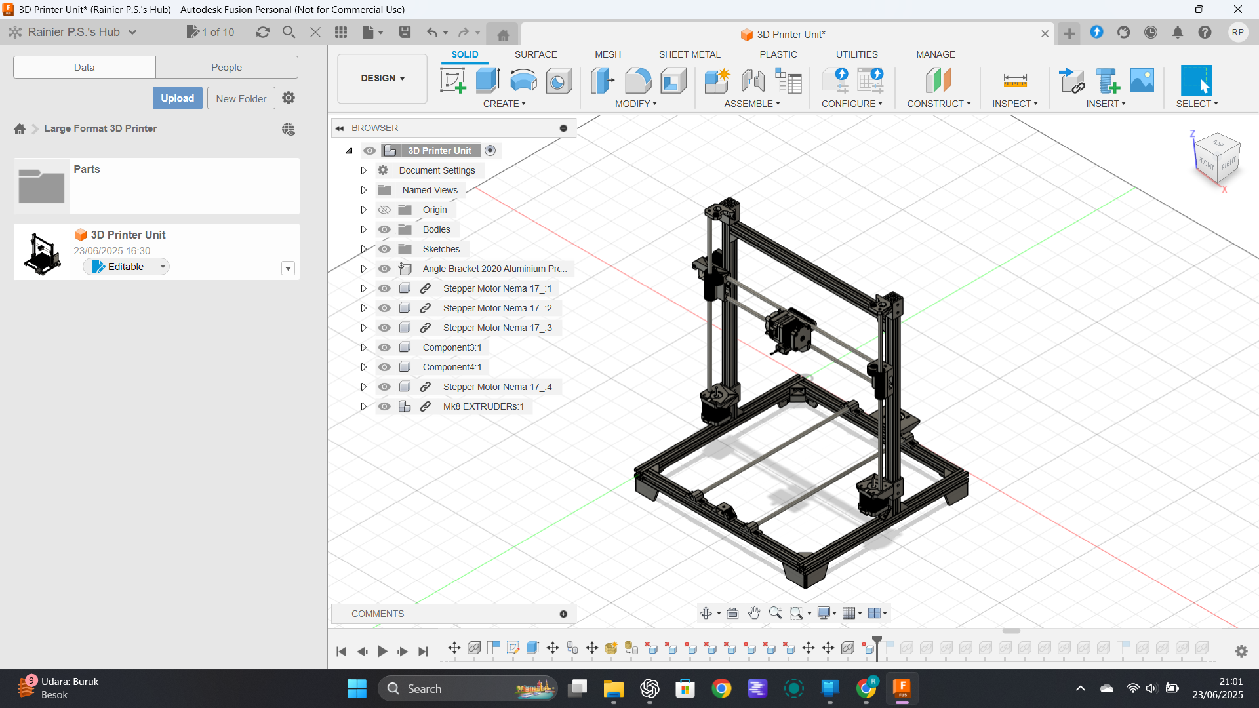
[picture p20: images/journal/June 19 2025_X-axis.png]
X-axis
* **Image:** 

---

## 20 June 2025

* **Time Spent:** 5 hours
* **Activities:**

  * Modeled bed carriage plate and linear bearing blocks
  * Added heated bed PCB to model
  * Added PSU and PSU mount to rear frame
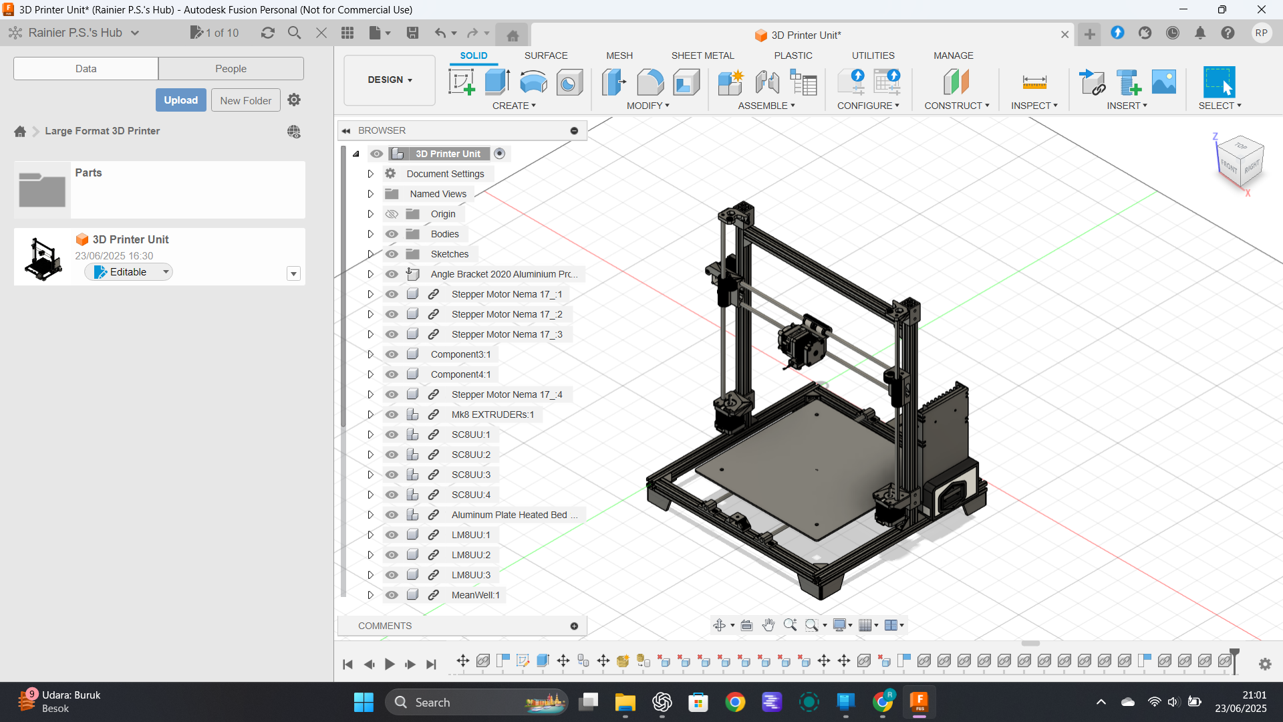
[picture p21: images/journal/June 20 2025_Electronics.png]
Electronics
* **Image:** 

---

## 21 June 2025

* **Time Spent:** 5 hours
* **Activities:**

  * Added display mount bracket and dimensions
  * Performed design cleanup and dimension review
  * Exported final screenshots and prepared CAD files
* **Image:** 3D Model

---

## 22 June 2025

* **Time Spent:** 6 hours
* **Activities:**

  * Started schematic design on EasyEDA
  * Wired motors, endstops, heaters, fans, and thermistors
  * Checked RAMPS 1.4 and TMC2209 compatibility
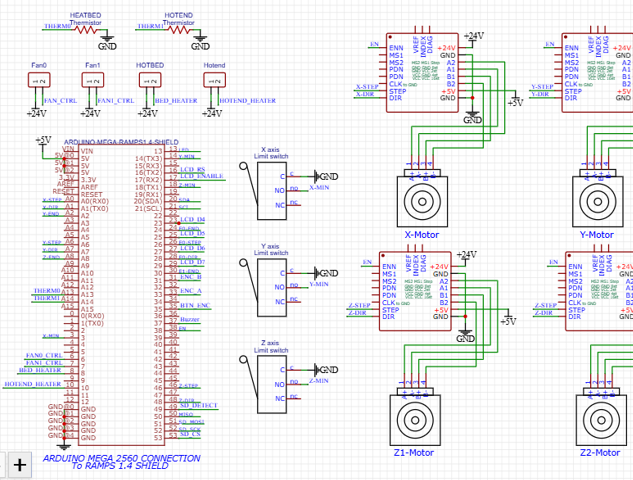
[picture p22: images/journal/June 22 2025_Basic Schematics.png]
Wiring Diagram
* **Image:** 

---

## 23 June 2025

* **Time Spent:** 5.5 hours
* **Activities:**

  * Completed wiring diagram and schematic labels
  * Created detailed schematic notes document Wiring Description
  * Uploaded final CAD, firmware, and wiring files to GitHub
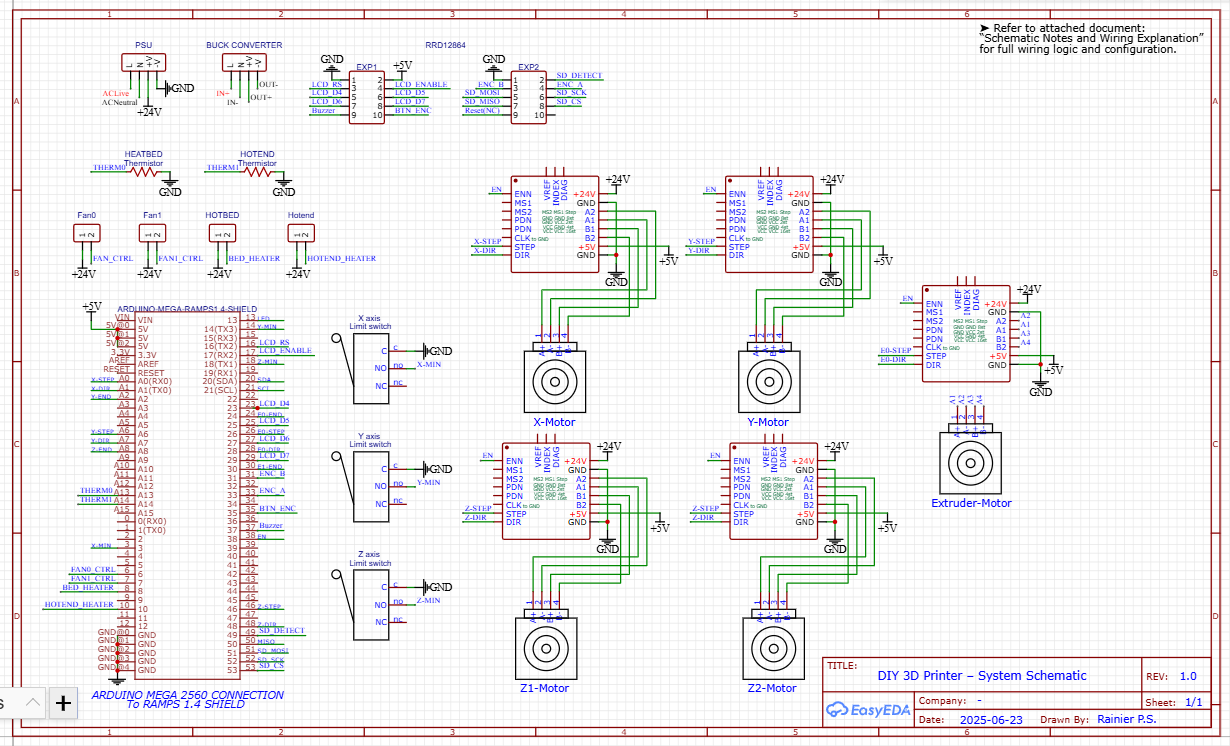
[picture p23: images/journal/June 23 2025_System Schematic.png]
System Schematic
* **Image:** 

---

## 24 June 2025

* **Time Spent:** 4 hours
* **Activities:**

  * Performed final  checks and refinements
  * Documented all refinements and adjustments
  * Prepared complete project submission
  * Verified all GitHub repository contents and documentation
  * Finalized README.md
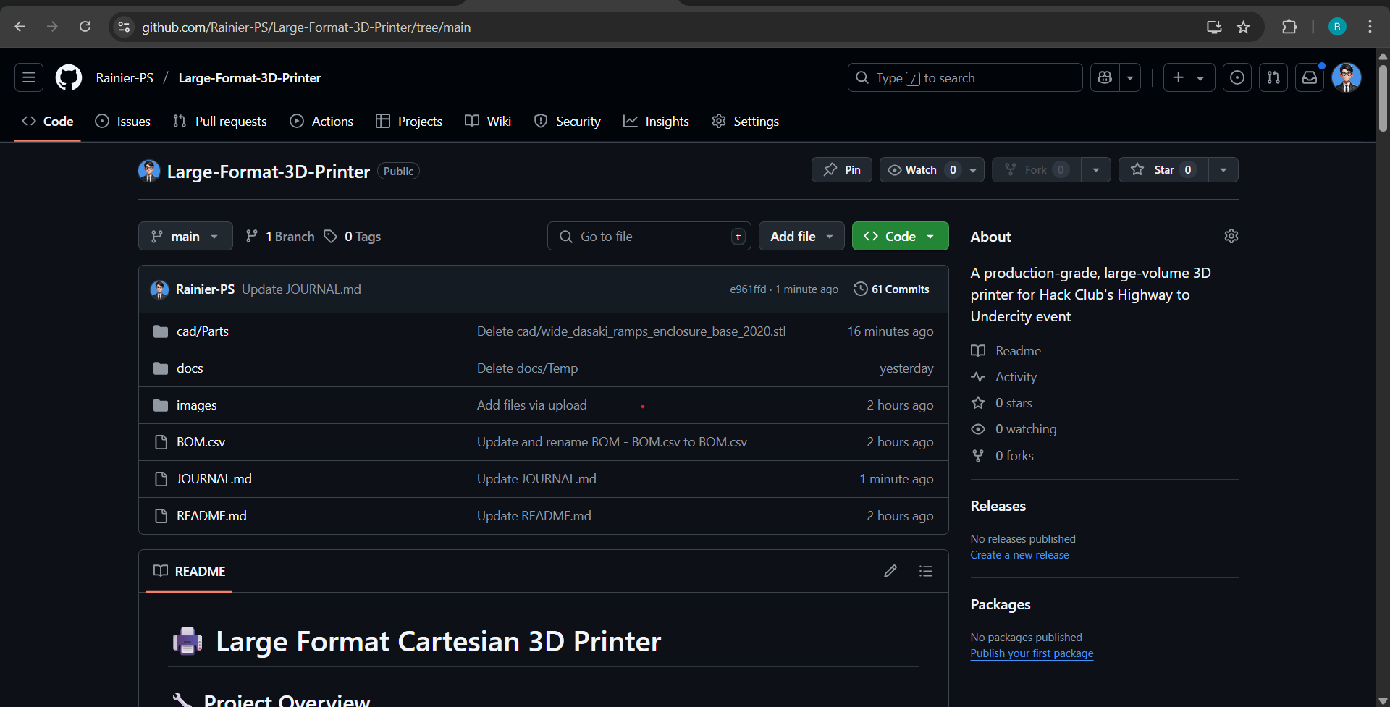
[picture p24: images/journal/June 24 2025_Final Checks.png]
Final Checks
* **Image:** 

---

> 📸 All images/screenshots are saved under the `/images/journal/` folder and referenced in the README.

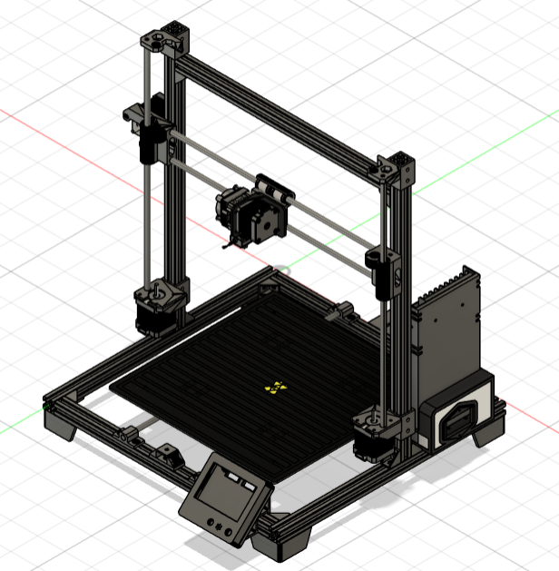
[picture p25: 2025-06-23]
images/journal/June 21 2025_3D Model.png

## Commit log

2025-06-24 Rename cad/4 x Foot.stl to cad/Parts/4 x Foot.stl
    [4 x Foot.stl]
2025-06-24 Rename cad/4 x Y_Rod_Mount.stl to cad/Parts/4 x Y_Rod_Mount.stl
    [4 x Y_Rod_Mount.stl]
2025-06-24 Rename cad/XZBOT3.stl to cad/Parts/Z-Axis Rod and Leadscrew Bracket.stl
    [Z-Axis Rod and Leadscrew Bracket.stl]
2025-06-24 Update and rename cad/dasaki_ramps_enclosure_cover_v2.stl to cad/Parts/dasaki_ramps_enclosure_cover_v2.stl
    [dasaki_ramps_enclosure_cover_v2.stl]
2025-06-24 Rename cad/prusa.remake.Z.hi.fix.0.5.stl to cad/Parts/Z-Axis Motor Mount.stl
    [Z-Axis Motor Mount.stl]
2025-06-24 Update and rename cad/x-end-idler.stl to cad/Parts/x-end-idler.stl
    [x-end-idler.stl]
2025-06-24 Update and rename cad/x-end-motor.stl to cad/Parts/x-end-motor.stl
    [x-end-motor.stl]
2025-06-24 Update and rename BOM - BOM.csv to BOM.csv
    [BOM.csv]
